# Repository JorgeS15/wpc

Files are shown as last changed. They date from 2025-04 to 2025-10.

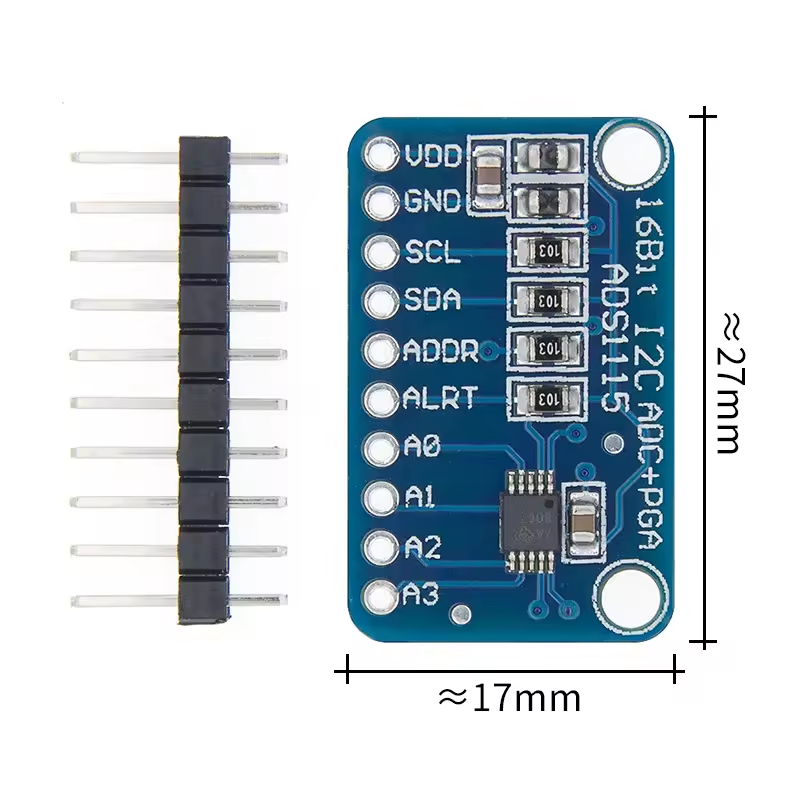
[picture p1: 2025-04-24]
wpc_datasheets/adc_ads1115_pinout.png

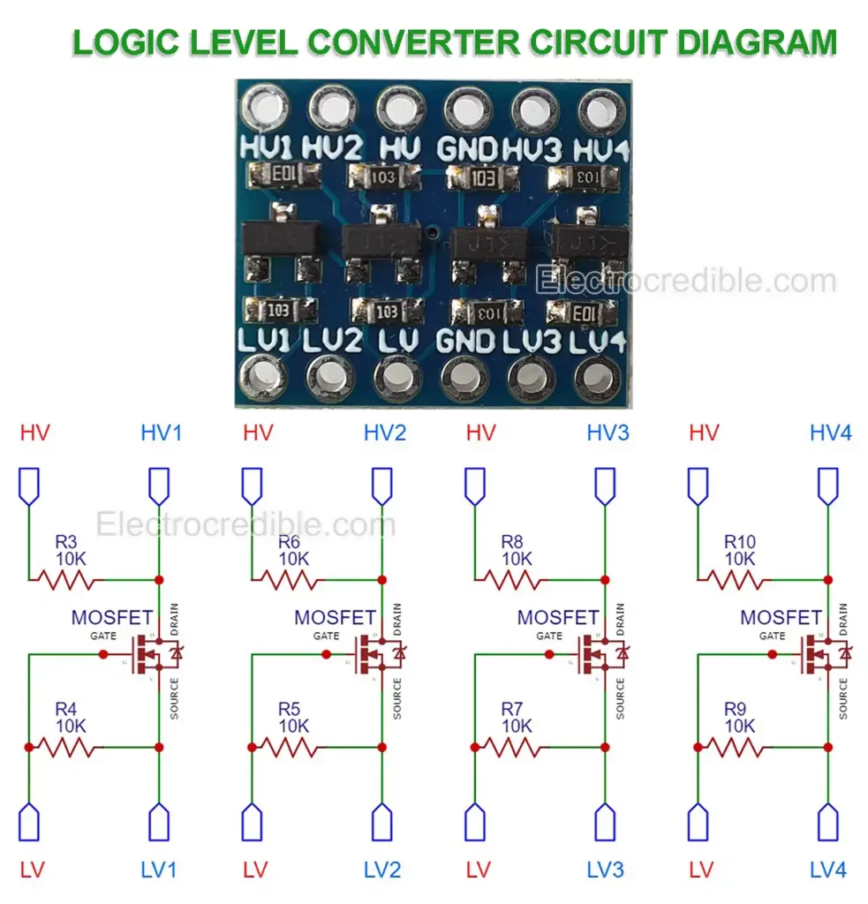
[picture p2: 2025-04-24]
wpc_datasheets/logic-level-converter-circuit-diagram.webp

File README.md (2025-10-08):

# Water Pressure Controller (WPC)

An intelligent water pressure monitoring and control system for well pumps, built on ESP32 and designed for seamless Home Assistant integration.

## Installation

See the [Installation Guide](INSTALLATION.md) for complete setup instructions.

## Overview

The Water Pressure Controller automatically regulates water pressure from well systems, providing real-time monitoring, safety features, and smart home integration. Built with ESP32 and programmed using Arduino IDE, this project offers a reliable and upgradable solution for managing well water systems.



## Features

- **Real-time Monitoring**
  - Water pressure tracking
  - Temperature measurement
  - Flow rate monitoring

- **Home Automation**
  - Home Assistant integration via MQTT
  - Remote monitoring and control
  - Status notifications

- **Safety & Protection**
  - Automatic error detection
  - Leak detection with automatic motor shutoff
  - Prevents pump damage and water waste

- **Easy Maintenance**
  - Over-The-Air (OTA) updates
  - No need for physical access to update firmware
  - Organized filesystem structure

- **Developer Friendly**
  - Clean, organized codebase
  - Modular filesystem architecture
  - Easily upgradable and customizable

mqtt

## Hardware Requirements

- ESP32 development board
- Pressure sensor (compatible with ESP32)
- Temperature sensor
- Flow sensor
- Relay module (for motor control)
- Well pump/motor
- Power supply

## Software Requirements

- Arduino IDE
- ESP32 board support for Arduino
- Required libraries (see `platformio.ini` or source files for dependencies)
- MQTT broker (for Home Assistant integration)

## Usage

Once installed and configured:

1. The system will automatically monitor water pressure, temperature, and flow
2. The pump motor will be controlled based on pressure thresholds
3. If a leak or error is detected, the motor will automatically shut off
4. Monitor all readings through Home Assistant dashboard
5. Update firmware remotely using OTA when updates are available

## Safety Features

- **Automatic Shutoff**: Motor stops immediately when leaks are detected
- **Pressure Monitoring**: Prevents over-pressurization
- **Error Detection**: Identifies and responds to system anomalies
- **Fail-safe Operation**: Default behavior ensures system safety

## License

This project is open source. Please check the repository for license information.

## Support

For issues, questions, or suggestions, please open an issue on the GitHub repository.

---

**Project Status**: Not in active development

**Maintainer**: [JorgeS15](https://github.com/JorgeS15)

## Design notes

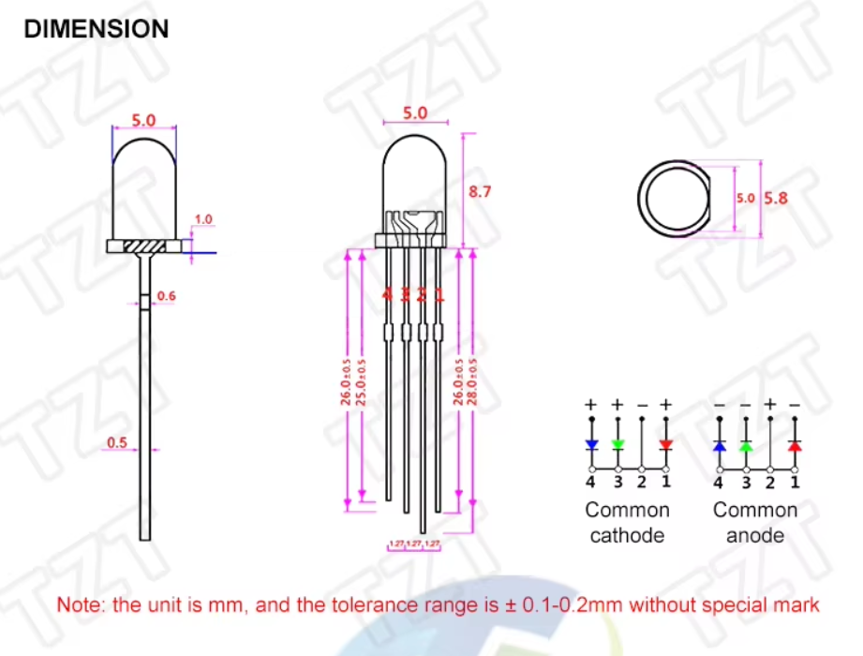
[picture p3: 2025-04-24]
wpc_datasheets/led_pinout.png

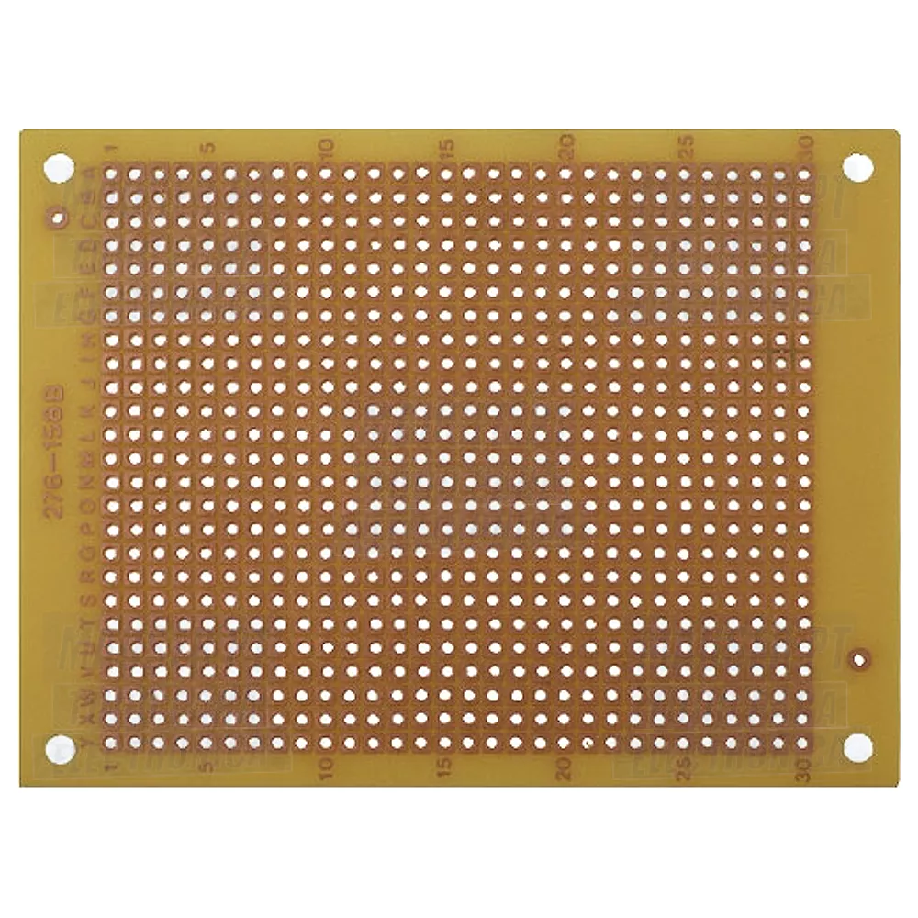
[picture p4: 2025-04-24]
wpc_datasheets/perfboard.webp

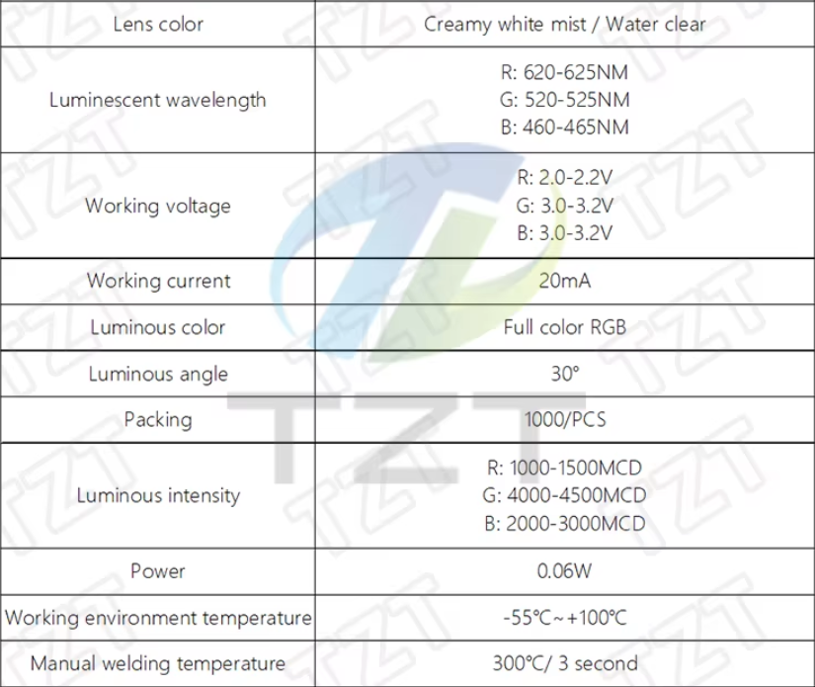
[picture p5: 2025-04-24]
wpc_datasheets/led_info.png

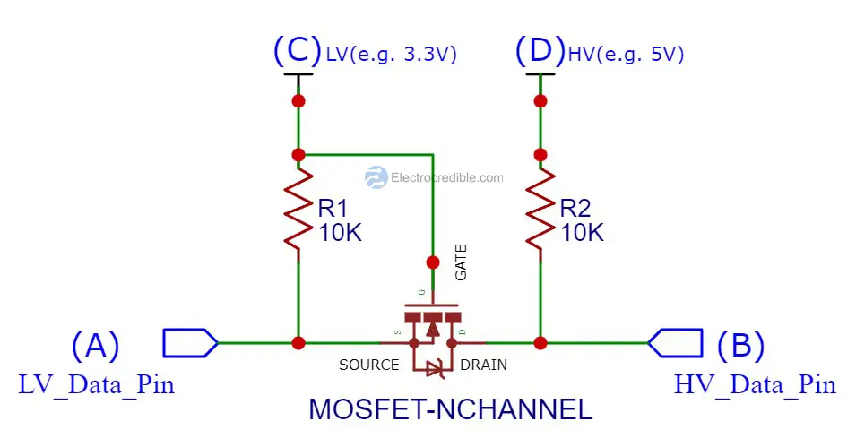
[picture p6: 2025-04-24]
wpc_datasheets/mosfet-bidirectional-logic-level-shifter.png

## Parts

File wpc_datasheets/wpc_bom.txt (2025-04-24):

ADC AS1115 - https://a.aliexpress.com/_EQk64E8
LED RGB - https://a.aliexpress.com/_EHmibTS
PERFBOARD  - https://mauser.pt/catalog/product_info.php?cPath=324_708_1565&products_id=096-1322
FLOW SENSOR - https://www.aliexpress.com/item/1005005588692911.html?spm=a2g0o.order_list.order_list_main.4.5aa7caa4hdLGbL

https://pt.aliexpress.com/item/1005005588692911.html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

Current Meter - https://pt.aliexpress.com/item/1005001771821385.html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

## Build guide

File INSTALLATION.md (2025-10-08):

# Installation Guide - Water Pressure Controller (WPC)

This guide will walk you through the complete installation process for the Water Pressure Controller project, including the crucial LittleFS filesystem setup.

## Table of Contents
- [Prerequisites](#prerequisites)
- [Step 1: Clone the Repository](#step-1-clone-the-repository)
- [Step 2: Install Arduino IDE and ESP32 Support](#step-2-install-arduino-ide-and-esp32-support)
- [Step 3: Install Required Libraries](#step-3-install-required-libraries)
- [Step 4: Install LittleFS Upload Tool](#step-4-install-littlefs-upload-tool)
- [Step 5: Prepare Configuration Files](#step-5-prepare-configuration-files)
- [Step 6: Upload LittleFS Filesystem](#step-6-upload-littlefs-filesystem)
- [Step 7: Configure Your Settings](#step-7-configure-your-settings)
- [Step 8: Upload the Sketch](#step-8-upload-the-sketch)
- [Step 9: Verify Installation](#step-9-verify-installation)
- [Troubleshooting](#troubleshooting)

---

## Prerequisites

Before you begin, make sure you have:
- An ESP32 development board
- USB cable for programming
- WiFi network credentials
- MQTT broker (local or cloud-based)
- Computer with Windows, macOS, or Linux

---

## Step 1: Clone the Repository

Open your terminal or command prompt and run:

```bash
git clone https://github.com/JorgeS15/wpc.git
cd wpc
```

---

## Step 2: Install Arduino IDE and ESP32 Support

### Install Arduino IDE

1. Download Arduino IDE 2.x from [arduino.cc](https://www.arduino.cc/en/software)
2. Install the downloaded package for your operating system
3. Launch Arduino IDE

### Add ESP32 Board Support

1. Open Arduino IDE
2. Go to **File → Preferences** (or **Arduino IDE → Settings** on macOS)
3. In the "Additional Board Manager URLs" field, add:
   ```
   https://raw.githubusercontent.com/espressif/arduino-esp32/gh-pages/package_esp32_index.json
   ```
4. Click **OK**
5. Go to **Tools → Board → Board Manager**
6. Search for "**ESP32**"
7. Install "**ESP32 by Espressif Systems**" (latest version)
8. Wait for the installation to complete

---

## Step 3: Install Required Libraries

1. Open Arduino IDE
2. Go to **Sketch → Include Library → Manage Libraries** (or click the Library Manager icon in the sidebar)
3. Search for and install each of the following libraries:

   - **PubSubClient** (by Nick O'Leary) - for MQTT communication
   - **ArduinoJson** (by Benoit Blanchon) - for JSON parsing
   - Any additional libraries that appear as errors when you first try to compile

4. Wait for all installations to complete

---

## Step 4: Install LittleFS Upload Tool

LittleFS is used to store configuration files, web interfaces, and other data on the ESP32's flash memory.

### For Arduino IDE 2.x (Recommended)

#### Option A: Install via Extensions Manager

1. Open Arduino IDE 2.x
2. Click the **Extensions** icon in the left sidebar (puzzle piece icon)
3. Search for "**arduino-littlefs-upload**"
4. Click **Install**
5. Restart Arduino IDE if prompted

#### Option B: Manual Installation

1. Visit the [arduino-littlefs-upload releases page](https://github.com/earlephilhower/arduino-littlefs-upload/releases)
2. Download the latest release (`.vsix` file)
3. In Arduino IDE:
   - Press `Ctrl+Shift+P` (Windows/Linux) or `Cmd+Shift+P` (macOS)
   - Type "**Extensions: Install from VSIX**"
   - Select the downloaded `.vsix` file
4. Restart Arduino IDE

### For Arduino IDE 1.x (Legacy)

1. Download the ESP8266LittleFS tool from [this repository](https://github.com/earlephilhower/arduino-esp8266littlefs-plugin)
2. Extract to your Arduino `tools` folder:
   - Windows: `C:\Users\[Username]\Documents\Arduino\tools\`
   - macOS: `~/Documents/Arduino/tools/`
   - Linux: `~/Arduino/tools/`
3. Restart Arduino IDE

---

## Step 5: Prepare Configuration Files

### Create or Verify the Data Folder

1. Navigate to your WPC sketch folder (where the `.ino` file is located)
2. Check if a `data/` folder exists
3. If it doesn't exist, create it manually

### Data Folder Structure

Your project should look like this:

```
wpc_code/
├── wpc_code.ino
├── data/
│   ├── app.js     
│   ├── index.html       
│   ├── style.css        
│   └── ...
└── other_files.cpp/h
```

---

## Step 6: Upload LittleFS Filesystem

**⚠️ IMPORTANT:** The LittleFS filesystem must be uploaded **BEFORE** or **SEPARATELY** from your sketch.

### Upload Process

1. **Connect your ESP32 board** via USB
2. **Select the correct board**:
   - Go to **Tools → Board**
   - Select your specific ESP32 board (e.g., "ESP32 Dev Module")
3. **Select the correct port**:
   - Go to **Tools → Port**
   - Select the COM port (Windows) or `/dev/ttyUSB*` (Linux) or `/dev/cu.usbserial-*` (macOS)
4. **Set partition scheme** (if available):
   - Go to **Tools → Partition Scheme**
   - Select a scheme with SPIFFS or appropriate storage (e.g., "Default 4MB with spiffs")

### Upload LittleFS

**For Arduino IDE 2.x:**

1. Press `Ctrl+Shift+P` (Windows/Linux) or `Cmd+Shift+P` (macOS)
2. Type "**Upload LittleFS**"
3. Select "**Upload LittleFS to Pico/ESP8266/ESP32**"
4. Wait for the upload to complete (may take several minutes depending on data size)
5. You should see "**LittleFS Image Uploaded**" in the output

**For Arduino IDE 1.x:**

1. Go to **Tools → ESP8266/ESP32 LittleFS Data Upload**
2. Wait for the upload to complete

### Verify Upload

Check the Arduino IDE output window for messages like:
```
LittleFS image created
LittleFS image uploaded
```

---

## Step 7: Configure Your Settings

Before uploading the main sketch, you may need to configure settings. This depends on how the project is set up:

### Option A: Configuration in Data Folder (Recommended)

If using a `config.json` or similar file in the `data/` folder:

1. Open `data/config.json` with a text editor
2. Update the following settings:

```json
{
  "wifi": {
    "ssid": "YourWiFiSSID",
    "password": "YourWiFiPassword"
  },
  "mqtt": {
    "broker": "192.168.1.100",
    "port": 1883,
    "username": "mqtt_user",
    "password": "mqtt_password",
    "topic": "home/water/pressure"
  },
  "sensors": {
    "pressure_calibration": 1.0,
    "temperature_offset": 0.0,
    "flow_sensor_factor": 4.5
  }
}
```

3. Save the file
4. **Re-upload the LittleFS filesystem** (repeat Step 6)

### Option B: Configuration in Code

If settings are hardcoded in the sketch:

1. Open the main `.ino` file
2. Look for configuration constants at the top (e.g., `WIFI_SSID`, `MQTT_BROKER`)
3. Update them with your values
4. Save the file

---

## Step 8: Upload the Sketch

Now that the filesystem is uploaded, upload the main program:

1. **Ensure your ESP32 is still connected**
2. **Close any open Serial Monitors** (important!)
3. Click the **Upload** button (→) in Arduino IDE, or press `Ctrl+U` / `Cmd+U`
4. Wait for compilation and upload to complete
5. You should see "**Done uploading**" when finished

---

## Step 9: Verify Installation

### Open Serial Monitor

1. Go to **Tools → Serial Monitor** or press `Ctrl+Shift+M` / `Cmd+Shift+M`
2. Set the baud rate to **115200** (or match what's in `Serial.begin()` in your code)
3. Press the **RESET** button on your ESP32

### Check for Proper Initialization

You should see output similar to:

```
Starting Water Pressure Controller...
LittleFS mounted successfully
Loading configuration...
Connecting to WiFi: YourSSID
WiFi connected! IP: 192.168.1.XXX
Connecting to MQTT broker...
MQTT connected!
System ready.
```

### Verify Functionality

- ✅ WiFi connection established
- ✅ MQTT connection successful
- ✅ Sensors initialized
- ✅ No error messages in Serial Monitor

---

## Troubleshooting

### LittleFS Upload Fails

**Problem:** "A fatal error occurred: Could not open port"

**Solutions:**
- Close all Serial Monitor windows
- Disconnect and reconnect the ESP32
- Try a different USB cable or port
- Check that no other program is using the COM port

---

**Problem:** "Error: Partition table does not include LittleFS"

**Solutions:**
- Go to **Tools → Partition Scheme**
- Select a partition scheme that includes SPIFFS/LittleFS storage
- Try "Default 4MB with spiffs (1.2MB APP/1.5MB SPIFFS)"

---

**Problem:** "Upload failed, error code: 2"

**Solutions:**
- Make sure the correct board is selected in **Tools → Board**
- Ensure the correct port is selected in **Tools → Port**
- Try putting the ESP32 in flash mode manually:
  - Hold **BOOT** button
  - Press **RESET** button
  - Release **RESET** button
  - Release **BOOT** button
  - Try upload again

---

### Files Not Being Read

**Problem:** Code can't read files from LittleFS

**Solutions:**
1. Verify LittleFS was mounted successfully (check Serial Monitor)
2. Check file paths in code - they should start with `/`:
   ```cpp
   File file = LITTLEFS.open("/config.json", "r");
   ```
3. Verify files exist on the filesystem:
   ```cpp
   if (!LITTLEFS.exists("/config.json")) {
       Serial.println("Config file not found!");
   }
   ```
4. Ensure LittleFS is initialized in your code:
   ```cpp
   if (!LITTLEFS.begin()) {
       Serial.println("LittleFS mount failed");
   }
   ```

---

### WiFi Connection Issues

**Problem:** ESP32 can't connect to WiFi

**Solutions:**
- Double-check SSID and password (case-sensitive!)
- Ensure your WiFi is 2.4GHz (ESP32 doesn't support 5GHz)
- Check if MAC address filtering is enabled on your router
- Try moving closer to the WiFi router
- Check Serial Monitor for specific error messages

---

### MQTT Connection Issues

**Problem:** Can't connect to MQTT broker

**Solutions:**
- Verify MQTT broker is running and accessible
- Check firewall settings on the broker
- Confirm broker IP address and port
- Test broker with an MQTT client tool (e.g., MQTT Explorer)
- Verify username/password if authentication is required
- Check Serial Monitor for connection error codes

---

### OTA Update Not Working

**Problem:** Over-The-Air updates fail

**Solutions:**
- Ensure ESP32 is connected to WiFi
- Check that OTA is properly initialized in code
- Verify the device is reachable on the network
- Try increasing the OTA partition size in partition scheme
- Make sure firewall isn't blocking OTA port

---

## Additional Resources

- **Project Repository:** https://github.com/JorgeS15/wpc
- **ESP32 Documentation:** https://docs.espressif.com/projects/arduino-esp32/
- **LittleFS Documentation:** https://github.com/littlefs-project/littlefs
- **PubSubClient (MQTT):** https://pubsubclient.knolleary.net/
- **Home Assistant MQTT:** https://www.home-assistant.io/integrations/mqtt/

---

## Next Steps

After successful installation:

1. **Configure Home Assistant** (if using) to subscribe to your MQTT topics
2. **Set up dashboards** for monitoring pressure, temperature, and flow
3. **Test leak detection** functionality in a safe environment
4. **Configure automation rules** for motor control
5. **Set up regular backups** of your configuration

---

## Support

If you encounter issues not covered in this guide:

1. Check the project's [Issues page](https://github.com/JorgeS15/wpc/issues)
2. Create a new issue with:
   - Your ESP32 board model
   - Arduino IDE version
   - Full Serial Monitor output
   - Steps to reproduce the problem

---

**Happy building! 🚰⚡**

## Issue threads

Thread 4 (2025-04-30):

Current Meters

JorgeS15, 2025-04-30:
I've already planned the hardware to have current meters for the pump's tri phase motor. It takes time to do some testing before implementing it.

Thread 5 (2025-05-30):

Not enought memory

JorgeS15, 2025-05-30:
Since updating is the firmware/littleFS is being hard (I believe due to memory being to full) I'm planning to add an SD Card for the files and have more room for firmware. This will come as v3 since I am also planning to add a new SPI ADC (for pressure sensors and current sensors).

No, optmizing the current system is not an option. I'll just do a few tweaks on the firmware side but I might keep the filesystem as it is.

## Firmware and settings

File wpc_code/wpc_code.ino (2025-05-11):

#include <math.h>
#include <Adafruit_ADS1X15.h>
#include <ArduinoJson.h>
#include <WiFi.h>
#include "LittleFS.h"
#include <AsyncTCP.h>
#include <ESPAsyncWebServer.h>
#include <ElegantOTA.h>
#include <PubSubClient.h>
#include <WiFiClient.h>
#include "mqtt_handler.h"

// Wi-Fi credentials
const char* SSID = "YOUR_WIFI_SSID";
const char* PASSWORD = "YOUR_WIFI_PASSWORD";

// MQTT configuration
const char* MQTT_SERVER = "YOUR_MQTT_IP";
const int MQTT_PORT = 1883;
const char* MQTT_USER = "YOUR_MQTT_USER";
const char* MQTT_PASSWORD = "YOUR_MQTT_PASSWORD";
const char* DEVICE_NAME = "wpc";
const char* DEVICE_ID = "wpc1";
const char* DEVICE_MANUFACTURER = "JorgeS15";
const char* DEVICE_MODEL = "Water Pressure Controller";
const char* DEVICE_VERSION = "2.1.0";

WiFiClient espClient;
PubSubClient mqttClient(espClient);
unsigned long lastMqttReconnectAttempt = 0;
const unsigned long MQTT_RECONNECT_INTERVAL = 5000;

// Pin definitions
#define MOTOR_PIN 19
#define LED_RED 16
#define LED_GREEN 17
#define LED_BLUE 18
#define FLOW_PIN 23
#define TEMP_PIN 35
#define ledPin 2

// Constants
const int NUM_SAMPLES = 50;
const int DELAY = 5;

const float PRESS1_OFFSET = 0.0;
const float TEMP_OFFSET = 0.16;
const float MIN_PRESS = 2.5;
const float MAX_PRESS = 3.5;

// Variables
volatile int pulseCount = 0;
unsigned long lastTime = 0;

//Measured values
float pressure = 0;
float temperature = 0;
float flow = 0;

bool ledState = false;
bool motor = false;
bool manualOverride = false;
bool manualMotorState = false;
bool mainSwitch = true;
bool lights = true;
bool error = false;
bool rebootRequested = false;

// Create AsyncWebServer object on port 80
AsyncWebServer server(80);
AsyncEventSource events("/events");

// Create an ADS1115 instance
Adafruit_ADS1115 ads;

// Track Wi-Fi status
bool wifiConnected = false;
unsigned long wifiReconnectInterval = 15000;
unsigned long lastWifiReconnectAttempt = 0;

void IRAM_ATTR pulseCounter() {
    pulseCount++;
}

void setup() {
    Serial.begin(115200);
    esp_reset_reason_t reset_reason = esp_reset_reason();
    Serial.print("Reset reason: ");
    Serial.println(reset_reason);
    initLittleFS();
    setupWiFi();
    mqttClient.setBufferSize(2048);
    setupMQTT();
    webRoutes();
    server.serveStatic("/", LittleFS, "/");
    server.addHandler(&events);
    ElegantOTA.begin(&server);
    server.begin();
    Serial.println("Web server started");
    setupPins();
    digitalWrite(MOTOR_PIN, LOW);
    lastTime = millis();
    digitalWrite(LED_RED, HIGH);

    if (!ads.begin()) {
        Serial.println("Failed to initialize ADS1115!");
        while(1);
    }

    Serial.println("ADS1115 initialized!");
    ads.setGain(GAIN_ONE);
    digitalWrite(LED_RED, LOW);
    delay(2000);
}

void loop() {
    ElegantOTA.loop();

    if (rebootRequested) {
        delay(1000);
        ESP.restart();
    }

    if (!wifiConnected && millis() - lastWifiReconnectAttempt > wifiReconnectInterval) {
        Serial.println("Attempting to reconnect to Wi-Fi...");
        lastWifiReconnectAttempt = millis();
        setupWiFi();
    }

    if (wifiConnected && !mqttClient.connected() && 
        millis() - lastMqttReconnectAttempt > MQTT_RECONNECT_INTERVAL) {
        lastMqttReconnectAttempt = millis();
        if (reconnectMQTT()) {
            lastMqttReconnectAttempt = 0;
        }
    }
    mqttClient.loop();
    
    unsigned long currentTime = millis();
    if (currentTime - lastTime >= 1000) { //Measures every second
        noInterrupts();
        flow = pulseCount / 8.0;
        pulseCount = 0;
        interrupts();
        lastTime = millis();
        
        pressure = readInPressure();
        temperature = readAverageTemperature();

        controlMotor(); //Controls Motor Logic
        updateLights(); //Control lights

        notifyClients(); //update WebPage
        publishState(); //publish MQTT
        updateSerial(); //Print Serial
    }
    checkForErrors();
}

void controlMotor(){
    if (mainSwitch) {
        if (manualOverride) {
            motor = manualMotorState;
        } else {
             if (pressure <= MIN_PRESS) {
                 motor = true;
             } else if (pressure >= MAX_PRESS) {
                motor = false;
            }
        }
     } else {
        motor = false;
    }
    digitalWrite(MOTOR_PIN, motor ? HIGH : LOW); //Control motor
}

void setupPins(){
    pinMode(FLOW_PIN, INPUT_PULLDOWN);
    attachInterrupt(digitalPinToInterrupt(FLOW_PIN), pulseCounter, RISING);
    pinMode(MOTOR_PIN, OUTPUT);
    pinMode(LED_RED, OUTPUT);
    pinMode(LED_GREEN, OUTPUT);
    pinMode(LED_BLUE, OUTPUT);
    pinMode(ledPin, OUTPUT);
}

void updateSerial(){
    Serial.print("Override: ");
    Serial.println(manualOverride ? "ON" : "OFF");
    Serial.print("Pressure: ");
    Serial.print(pressure);
    Serial.println(" bar");
    Serial.print("Motor status (logic): ");
    Serial.println(motor ? "ON" : "OFF");
}

void updateLights() {
    if(lights){
        if (error) {
            // Error state - Red blinking
            digitalWrite(LED_RED, (millis() % 1000) < 500);
            digitalWrite(LED_GREEN, LOW);
            digitalWrite(LED_BLUE, LOW);
        }
        else if (!mainSwitch) {
            // System off - Solid red
            digitalWrite(LED_RED, HIGH);
            digitalWrite(LED_GREEN, LOW);
            digitalWrite(LED_BLUE, LOW);
        } 
        else if (manualOverride) {
            // Manual mode - Yellow
            digitalWrite(LED_RED, !motor ? HIGH : LOW);
            digitalWrite(LED_GREEN, !motor ? HIGH : LOW);
            digitalWrite(LED_BLUE, motor ? HIGH : LOW);
        } 
        else {
            // Auto mode waiting - Green
            digitalWrite(LED_RED, LOW);
            digitalWrite(LED_GREEN, !motor ? HIGH : LOW);
            digitalWrite(LED_BLUE, motor ? HIGH : LOW);
        }
    }
    else{ //Lights Off
        digitalWrite(LED_RED, LOW);
        digitalWrite(LED_GREEN, LOW);
        digitalWrite(LED_BLUE, LOW);
    }
}

float readInPressure() {
    float voltagePressure = readAveragePressure(0);
    float press = (1.25 * voltagePressure) - 0.625 + PRESS1_OFFSET;
    return press;
}

float readAverageTemperature() {
    float total = 0.0;
    for (int i = 0; i < NUM_SAMPLES; i++) {
        total += analogRead(TEMP_PIN);
        delay(DELAY);
    }
    float temp_voltage = total / NUM_SAMPLES * (3.3 / 4096.0) + TEMP_OFFSET;
    float temp_resistance = 97 * (1/ ((3.3/temp_voltage) - 1));
    float temp = -26.92 * log(temp_resistance) + 0.0796 * temp_resistance + 126.29;
    return temp;
}

float readAveragePressure(int pin) {
    float total = 0.0;
    for (int i = 0; i < NUM_SAMPLES; i++) {
        total += readFromADS1115(pin);
        delay(DELAY);
    }
    return (total / NUM_SAMPLES);
}

float readFromADS1115(uint8_t channel) {
    int16_t rawValue = ads.readADC_SingleEnded(channel);
    float voltage = rawValue * (4.096 / 32768.0);
    return voltage;
}

void checkForErrors() {
    if(!manualOverride){
        if (pressure < 2.0 || pressure > 4) {
            error = true;
        }
    }
    if(error){
        motor = false;
        mainSwitch = false;
    }
}

void setupWiFi() {
    WiFi.mode(WIFI_STA);
    Serial.print("Connecting to ");
    Serial.println(SSID);
    WiFi.begin(SSID, PASSWORD);
    
    unsigned long startAttemptTime = millis();
    while (WiFi.status() != WL_CONNECTED && millis() - startAttemptTime < 15000) {
        delay(500);
        Serial.print(".");
    }

    if (WiFi.status() == WL_CONNECTED) {
        Serial.print("\nConnected to ");
        Serial.println(SSID);
        Serial.print("IP Address: ");
        Serial.println(WiFi.localIP());
        wifiConnected = true;
    } else {
        Serial.println("\nFailed to connect to WiFi. Running in offline mode.");
        wifiConnected = false;
    }
}

void initLittleFS() {
    if (!LittleFS.begin(true)) {
        Serial.println("An error has occurred while mounting LittleFS");
    }
    else {
        Serial.println("LittleFS mounted successfully");
    }
}

void notifyClients() {
    DynamicJsonDocument doc(256);
    doc["pressure"] = pressure;
    doc["temperature"] = temperature;
    doc["flow"] = flow;
    doc["motor"] = motor;
    doc["manualOverride"] = manualOverride;
    
    String json;
    serializeJson(doc, json);
    
    Serial.println("Sending: " + json);
    events.send(json.c_str(), "update", millis());
}

void webRoutes(){
    // Route for root / web page (with authentication)
    server.on("/", HTTP_GET, [](AsyncWebServerRequest *request) {
        request->send(LittleFS, "/index.html", "text/html");
    });

    server.on("/app.js", HTTP_GET, [](AsyncWebServerRequest *request){
        request->send(LittleFS, "/app.js", "application/javascript");
    });
    //diagnotics page 
    server.on("/diagnostics", HTTP_GET, [](AsyncWebServerRequest *request) {
        DynamicJsonDocument doc(512);
        doc["uptime"] = millis() / 1000;
        doc["heap"] = ESP.getFreeHeap();
        doc["resetReason"] = esp_reset_reason();
        doc["wifiStrength"] = WiFi.RSSI();
        
        String json;
        serializeJson(doc, json);
        request->send(200, "application/json", json);
    });

    server.on("/reboot", HTTP_POST, [](AsyncWebServerRequest *request) {
        rebootRequested = true;
        request->send(200, "application/json", "{\"status\":\"ok\"}");
    });

    server.on("/command", HTTP_POST, [](AsyncWebServerRequest *request) {
    }, NULL, [](AsyncWebServerRequest *request, uint8_t *data, size_t len, size_t index, size_t total) {
        DynamicJsonDocument doc(128);
        DeserializationError error = deserializeJson(doc, data, len);
        
        if (!error) {
            if (doc.containsKey("command")) {
                String command = doc["command"];
                if (command == "toggle") {
                    manualOverride = true;
                    manualMotorState = !manualMotorState;
                } else if (command == "override") {
                    manualOverride = !manualOverride;
                }
                
                notifyClients();
                publishState();
                request->send(200, "application/json", "{\"status\":\"ok\"}");
                return;
            }
        }
        request->send(400, "application/json", "{\"error\":\"invalid request\"}");
    });

    events.onConnect([](AsyncEventSourceClient *client) {
        Serial.println("Client connected to /events");
        notifyClients();
    });
}

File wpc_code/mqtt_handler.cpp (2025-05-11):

#include "mqtt_handler.h"
#include <PubSubClient.h>
#include <ArduinoJson.h>

// MQTT client object
extern PubSubClient mqttClient;

void setupMQTT() {
    mqttClient.setServer(MQTT_SERVER, MQTT_PORT);
    mqttClient.setCallback(mqttCallback);
    sendAutoDiscoveryConfigs();
}

void mqttCallback(char* topic, byte* payload, unsigned int length) {
    // Convert payload to string
    String message;
    for (int i = 0; i < length; i++) {
        message += (char)payload[i];
    }
    
    Serial.print("MQTT message arrived [");
    Serial.print(topic);
    Serial.print("]: ");
    Serial.println(message);

    // Define command topics
    String motorTopic = String("homeassistant/") + DEVICE_ID + "/motor/set";
    String overrideTopic = String("homeassistant/") + DEVICE_ID + "/override/set";
    String mainTopic = String("homeassistant/") + DEVICE_ID + "/main/set";
    String errorTopic = String("homeassistant/") + DEVICE_ID + "/error/set";
	String rebootTopic = String("homeassistant/") + DEVICE_ID + "/reboot/set";

    // Handle incoming commands
    if (String(topic) == motorTopic) {
        manualMotorState = (message == "ON");
        Serial.print("Manual motor control set to: ");
        Serial.println(manualMotorState ? "ON" : "OFF");
    } 
    else if (String(topic) == overrideTopic) {
        manualOverride = (message == "ON");
        Serial.print("Manual override set to: ");
        Serial.println(manualOverride ? "ON" : "OFF");
    }
    else if (String(topic) == mainTopic) {
        mainSwitch = (message == "ON");
        Serial.print("Main switch set to: ");
        Serial.println(mainSwitch ? "ON" : "OFF");
    }
    else if (String(topic) == errorTopic) {
        error = (message == "ON");
        Serial.print("Error state set to: ");
        Serial.println(error ? "ON" : "OFF");
    }
	else if (String(topic) == rebootTopic && message == "PRESS") 
	{
		Serial.println("Reboot requested via MQTT");
		rebootRequested = true;
	}

    publishState();
}

bool reconnectMQTT() {
    if (mqttClient.connect(DEVICE_ID, MQTT_USER, MQTT_PASSWORD)) {
        Serial.println("MQTT connected");
        
        // Subscribe to all command topics
        String motorTopic = String("homeassistant/") + DEVICE_ID + "/motor/set";
        String overrideTopic = String("homeassistant/") + DEVICE_ID + "/override/set";
        String mainTopic = String("homeassistant/") + DEVICE_ID + "/main/set";
        String errorTopic = String("homeassistant/") + DEVICE_ID + "/error/set";
        
        mqttClient.subscribe(motorTopic.c_str());
        mqttClient.subscribe(overrideTopic.c_str());
        mqttClient.subscribe(mainTopic.c_str());
        mqttClient.subscribe(errorTopic.c_str());
        
        Serial.println("Subscribed to command topics:");
        Serial.println(motorTopic);
        Serial.println(overrideTopic);
        Serial.println(mainTopic);
        Serial.println(errorTopic);
        
        sendAutoDiscoveryConfigs();
        return true;
    }
    Serial.print("MQTT connection failed, rc=");
    Serial.println(mqttClient.state());
    return false;
}

void publishState() {
    if (!mqttClient.connected()) return;

    DynamicJsonDocument doc(256);
    doc["pressure"] = pressure;
    doc["temperature"] = temperature;
    doc["flow"] = flow;
    doc["motor"] = motor ? "ON" : "OFF";
    doc["override"] = manualOverride ? "ON" : "OFF";
    doc["main"] = mainSwitch ? "ON" : "OFF";
    doc["error"] = error ? "ON" : "OFF";
	doc["reboot_requested"] = rebootRequested;
    
    String state;
    serializeJson(doc, state);
    
    String stateTopic = String("homeassistant/") + DEVICE_ID + "/state";
    mqttClient.publish(stateTopic.c_str(), state.c_str(), true);
    
    Serial.print("Published state: ");
    Serial.println(state);
}

void sendAutoDiscoveryConfigs() {
    if (!mqttClient.connected()) return;

    Serial.println("Sending auto-discovery configs...");
    
    // Device configuration
    DynamicJsonDocument deviceDoc(256);
    deviceDoc["identifiers"] = DEVICE_ID;
    deviceDoc["name"] = DEVICE_NAME;
    deviceDoc["manufacturer"] = DEVICE_MANUFACTURER;
    deviceDoc["model"] = DEVICE_MODEL;
    deviceDoc["sw_version"] = DEVICE_VERSION;

    // Common state topic
    String stateTopic = String("homeassistant/") + DEVICE_ID + "/state";

    // Pressure sensor
    createSensorConfig(
        "pressure", 
        "Pressure", 
        "bar", 
        "pressure",
        "mdi:gauge",
        deviceDoc,
        stateTopic,
        "pressure"
    );

    // Temperature sensor
    createSensorConfig(
        "temperature", 
        "Temperature", 
        "°C", 
        "temperature",
        "mdi:thermometer",
        deviceDoc,
        stateTopic,
        "temperature"
    );

    // Flow sensor
    createSensorConfig(
        "flow", 
        "Flow Rate", 
        "L/min", 
        nullptr,
        "mdi:water",
        deviceDoc,
        stateTopic,
        "flow"
    );

    // Motor switch
    createSwitchConfig(
        "motor",
        "Pump Motor",
        "mdi:pump",
        deviceDoc,
        stateTopic,
        "motor",
        String("homeassistant/") + DEVICE_ID + "/motor/set"
    );
    
    // Main Switch
    createSwitchConfig(
        "main",
        "Main Power",
        "mdi:power",
        deviceDoc,
        stateTopic,
        "main",
        String("homeassistant/") + DEVICE_ID + "/main/set"
    );

    // Override switch
    createSwitchConfig(
        "override",
        "Manual Override",
        "mdi:account-wrench",
        deviceDoc,
        stateTopic,
        "override",
        String("homeassistant/") + DEVICE_ID + "/override/set"
    );
    
    createSwitchConfig(
        "error",
        "System Error",
        "mdi:alert",
        deviceDoc,
        stateTopic,
        "error",
        String("homeassistant/") + DEVICE_ID + "/error/set"
    );
	
	createButtonConfig(
		"reboot",
		"Reboot Device",
		"mdi:restart",
		deviceDoc,
		String("homeassistant/") + DEVICE_ID + "/reboot/set"
	);
}

void createSensorConfig(const char* sensorId, const char* name, const char* unit, 
                      const char* deviceClass, const char* icon,
                      JsonDocument& deviceDoc, const String& stateTopic,
                      const char* valueKey) {
    String configTopic = String("homeassistant/sensor/") + DEVICE_ID + "_" + sensorId + "/config";
    
    DynamicJsonDocument doc(512);
    doc["name"] = name;
    doc["unique_id"] = String(DEVICE_ID) + "_" + sensorId;
    doc["state_topic"] = stateTopic;
    doc["value_template"] = String("{{ value_json.") + valueKey + " }}";
    if (unit) doc["unit_of_measurement"] = unit;
    if (deviceClass) doc["device_class"] = deviceClass;
    if (icon) doc["icon"] = icon;
    doc["device"] = deviceDoc;
    
    publishDiscovery(configTopic, doc);
}
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

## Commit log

2025-04-30 eletrical corrections
    - schematic correction (sensors, actuation)
    - main board correction (resistor values, chottky diodes) (v26)
    [actuation.kicad_sch, auxiliar.kicad_sch, cabos.kicad_sch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]
2025-05-11 added mqtt integration
    mqtt intregation:
    - mqtt_handler.h
    - mqtt_handler.ccp
    Added reboot button and error state
    [mqtt_handler.cpp, wpc_code.ino]
2025-05-11 Update README.md
    -mqtt integration
    -webpage print added
